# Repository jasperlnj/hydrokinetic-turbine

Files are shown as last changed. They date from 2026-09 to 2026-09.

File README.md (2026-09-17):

# Hydrokinetic Turbogenerator

This repository documents a run-of-river turbogenerator I designed, built, and field-tested over the course of a year. The core idea was to use 3D-printed vertical-axis turbines to drive a repurposed brushless hub motor acting as a three-phase generator.

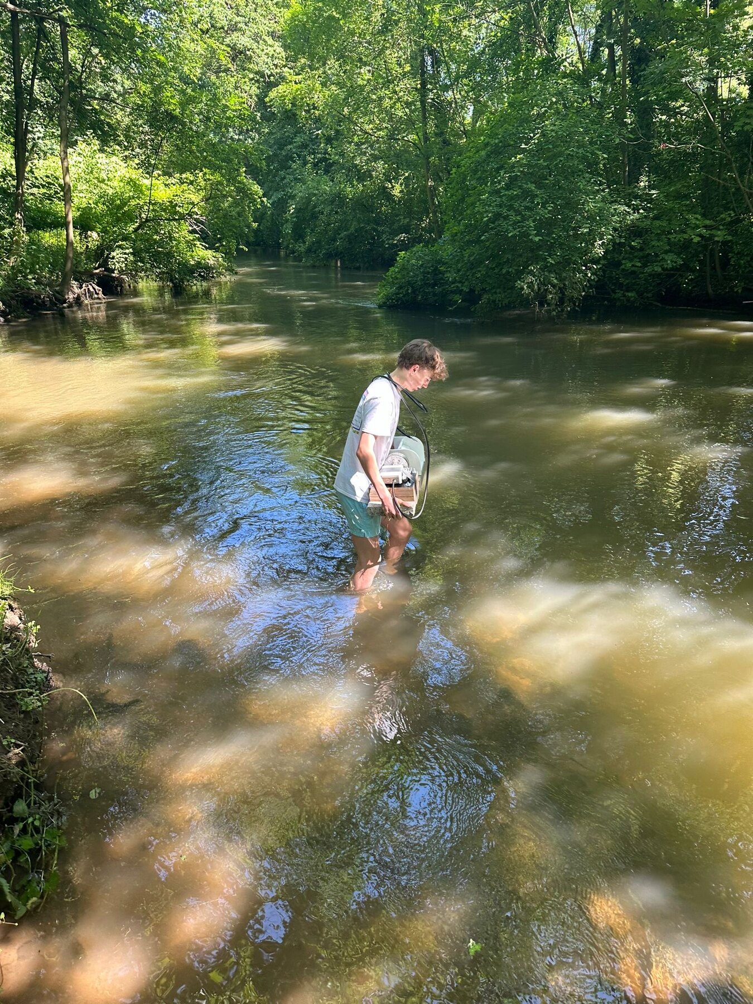
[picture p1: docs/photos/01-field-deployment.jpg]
Carrying the rig into the river Erft for the field test


**Spoiler alert: it didn't work.** The turbine refused to turn in the river.
But even though this was highly frustrating at first, it taught me some very valuable engineering lessons.

## Context

I originally built this for my *Projektkurs Naturwissenschaften* thesis at Friedrich-Wilhelm-Gymnasium in June 2024, right before I started my mechanical engineering degree at ETH Zürich.

The goal was to see if a small, fully 3D-printable hydrokinetic generator could produce usable power from a standard river current without needing a dam. I wanted to build something that could theoretically be carried out to a remote location to provide off-grid power.

If you read German, you can find my full original report here: [`docs/report-de.pdf`](docs/report-de.pdf).

## What I Built

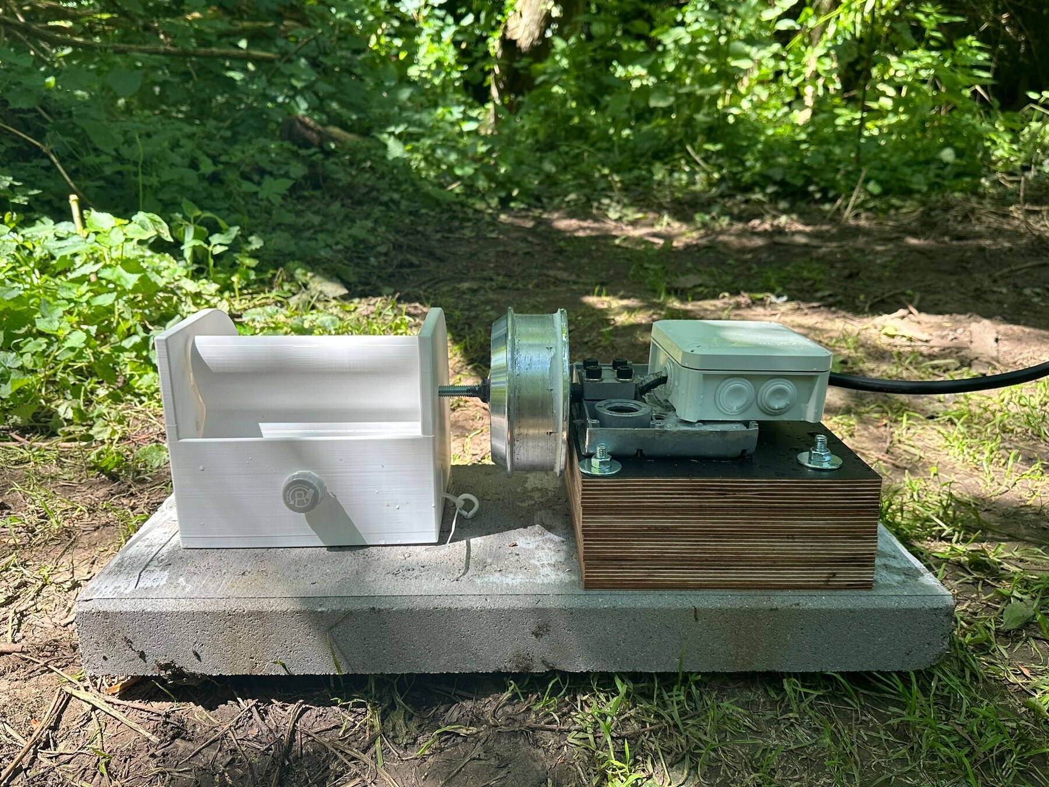
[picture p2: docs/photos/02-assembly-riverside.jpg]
The complete rig at the riverbank


The setup in the photo above (left to right) includes the 3D-printed turbine housing, the recycled electrical motor generator connected to the turbine using a threaded shaft, the motor mount, and a sealed junction box holding the rectifier.

The entire assembly is anchored to a heavy concrete paving slab, which was a late addition. My original design was way too light and kept getting pushed around by the flowing water. This way it was stable.

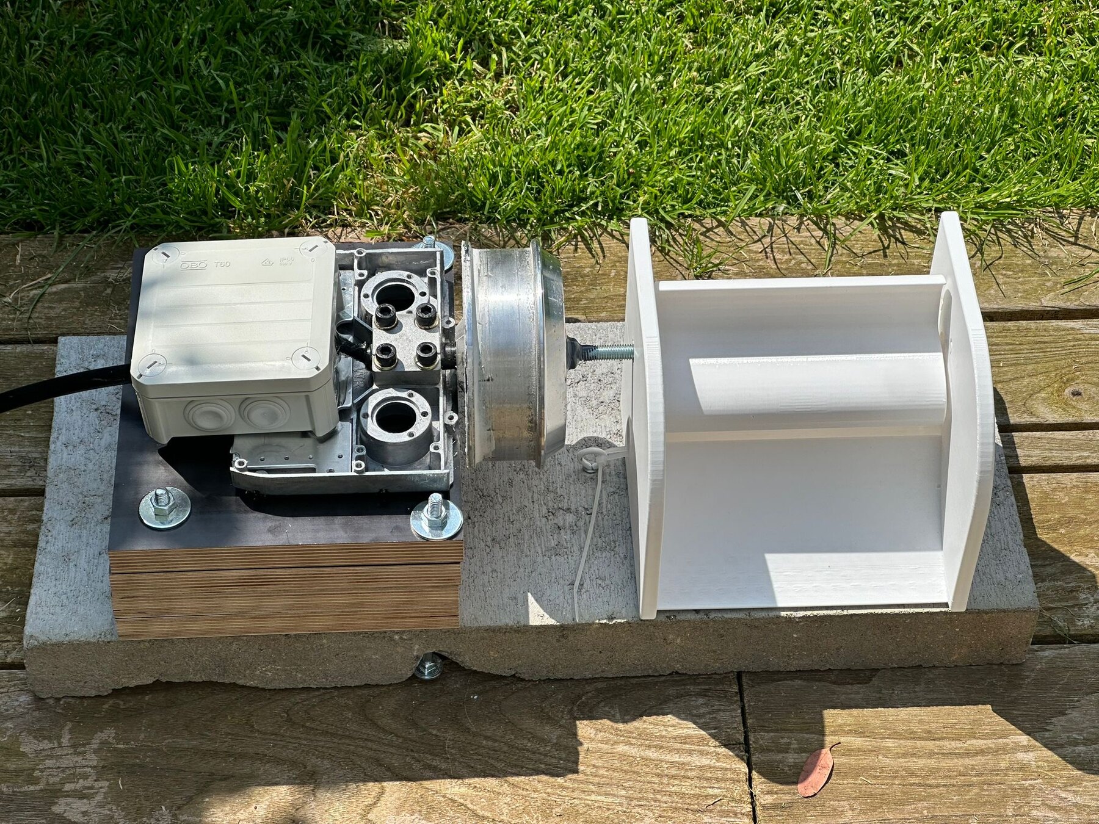
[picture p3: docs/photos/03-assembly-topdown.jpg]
Component layout from above


### The Turbines

I wanted to test different geometries, so I printed and weighed ten different vertical-axis turbine variants. I designed the main housing around a reversible fit, meaning I could quickly swap out any turbine by the riverside without having to rebuild the entire rig.

I played with three main variables:
- **Blade count:** 3, 4, 5, or 6 blades.
- **Blade shape:** Straight vs. curved.
- **Add-ons:** Guide vanes, higher mass or just plain.

All the variants fit into the same physical envelope (170 mm tall, 86–100 mm in diameter) and weighed between 90 g and 158 g. Unsurprisingly, more blades meant more mass. The variant with guide vanes was the heaviest by far—about 30% heavier than the plain three-blade version—which unfortunately put a significantly higher load on the generator's bearings.

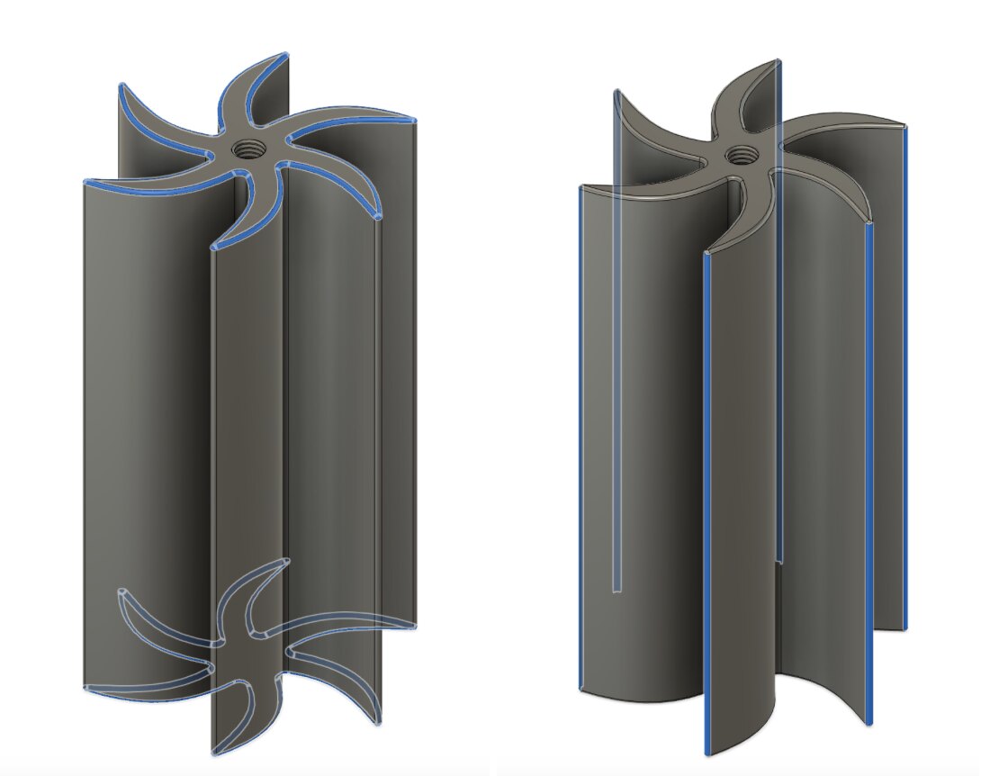
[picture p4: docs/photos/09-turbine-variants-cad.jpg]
Curved and straight blade variants


### The Generator & Rectifier

For the generator, I recycled a hoverboard hub motor, stripped it down, and ran it in reverse as a three-phase permanent magnet generator.

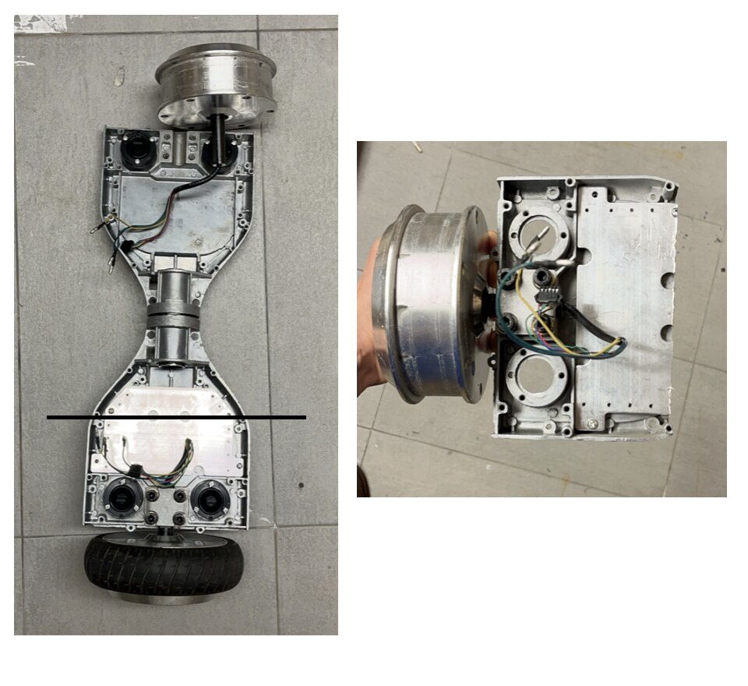
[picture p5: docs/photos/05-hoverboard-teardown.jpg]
Hoverboard hub motor teardown

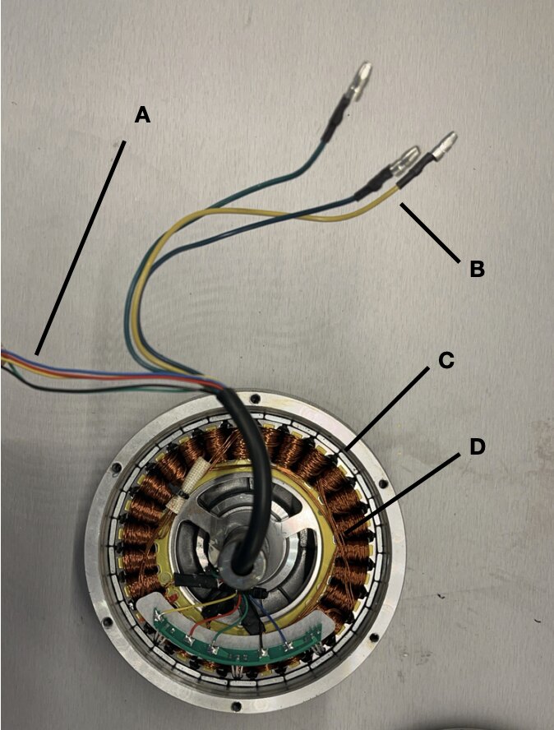
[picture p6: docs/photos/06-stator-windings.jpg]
Stator windings and phase leads


To make the three-phase AC output usable, I built a six-diode full bridge rectifier, sealed inside a waterproof junction box.
*(Circuit diagram: [`docs/rectifier-circuit.pdf`](docs/rectifier-circuit.pdf))*

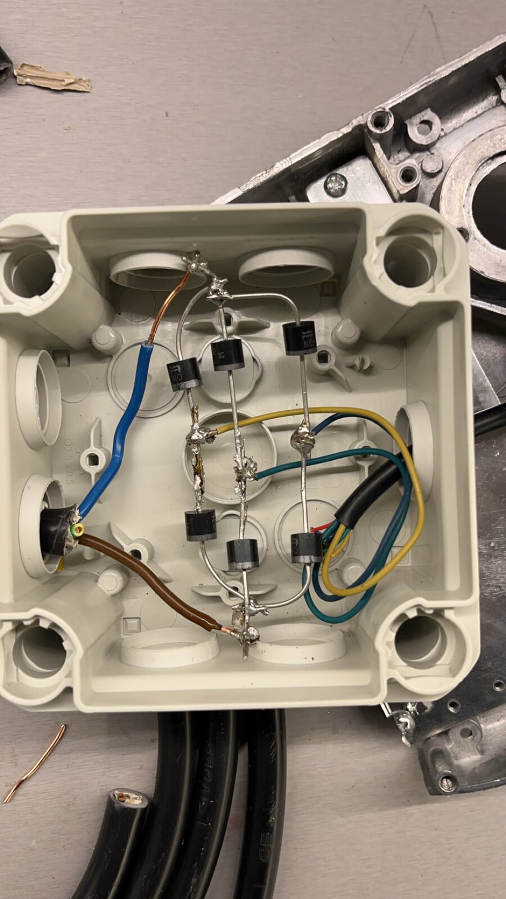
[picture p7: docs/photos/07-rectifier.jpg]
The rectifier bridge in its housing


## The Results

At first, things looked promising. When I gave it a good spin by hand, it generated 4.19 V across 3.41 A into a 20 Ω load. That is roughly **14.3 W**. The generator and the rectifier were doing their jobs perfectly.
I then took the setup out to the River Erft in Bergheim. I clocked the flow velocity at **1.468 m/s** (using the highly scientific method of timing a leaf floating down a 10-meter stretch). I sank the rig onto the riverbed so the turbine was about 20 cm below the surface, perfectly perpendicular to the flow.

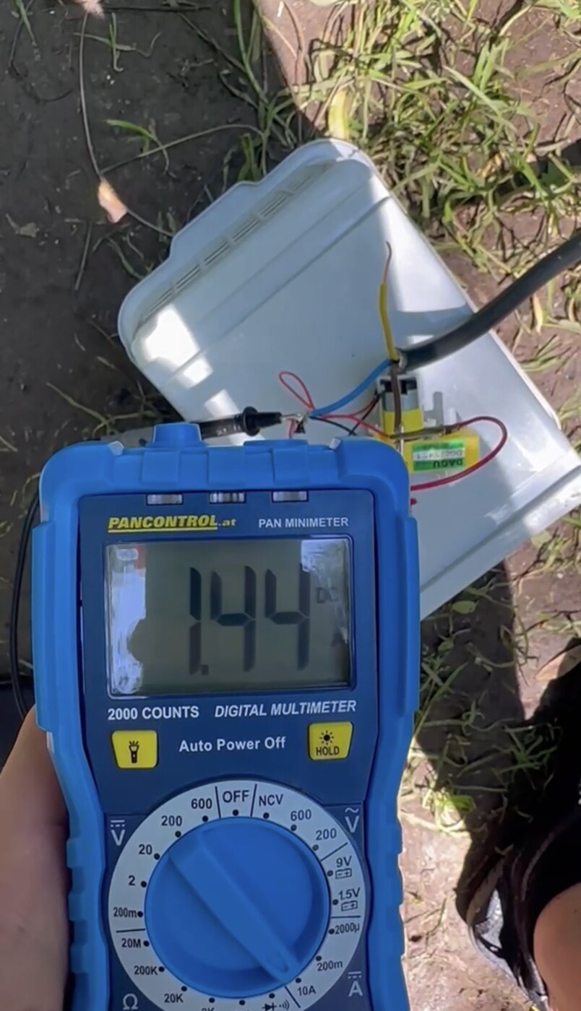
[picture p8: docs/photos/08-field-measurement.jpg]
Measuring output at the riverbank


When I reached under the water and spun it manually, it put out 1.64 V at 1.21 A (about **2.0 W**) and coasted for a second or two before the drag of the generator stopped it completely. The one major win was that the whole assembly stayed completely watertight, which was honestly the part I expected to fail first.

Because the turbine never maintained a steady speed under its own power, I couldn't measure a real power coefficient ($c_p$). If we assume a realistic $c_p \approx 0.1$, my original report projected it should have produced about 2.28 W.

## Why it didn't turn

The kinetic power passing through the turbine's swept area ($A = 0.01439 \text{ m}^2$, $v = 1.468 \text{ m/s}$) is:

$$P = \frac{1}{2}\rho A v^{3} = \frac{1}{2} \cdot 1000 \cdot 0.01439 \cdot 1.468^{3} \approx 22.8 \text{ W}$$

Even if we cap the efficiency at the theoretical Betz limit ($c_p \le 0.593$), there was roughly 13 W physically available to extract.

The real bottleneck was starting torque needed and not just the power available.
I fell into the trap of designing for power and completely ignored the torque required to get the system moving from a dead stop. Two specific mechanisms killed the rotation:

1. **Cogging torque:** A permanent-magnet hub motor has a really strong magnetic detent because the magnets want to align with the stator teeth. The river current has to break that static friction before anything moves and a stationary turbine generates drastically less torque than one that is already spinning.
2. **The diode bridge threshold:** The full bridge rectifier will not conduct until the generated voltage hits about 1.2–1.4 V. Below that speed, the generator is basically acts like a mechanical brake on the shaft without pushing any useful power out. The turbine has to fight its way out of this electrical "dead band" just to start doing work.

A basic power balance told me this project would work. A torque balance at zero speed would have told me it was doomed before I printed anything with the 3D-printer. Learning the critical distinction between a system being power-limited versus torque-limited at startup was my biggest takeaway from this whole endeavor, and it applies to almost any direct-drive machine.

## What I would do differently

If I were to build a version two, here is exactly what I would change:

- **Measure torque first:** I would put the generator on a bench, measure its exact cogging torque and no-load drag, and then size the turbine specifically to overcome that drag at my target flow velocity before committing to a blade geometry. Alternatively, I could reverse the process and select a motor matched to the turbine's output.
- **swap the motor:** Alternatively, I could reverse the process and select a motor matched to the turbine's output. Direct-driving a hoverboard motor designed for 20 km/h with a 1.5 m/s water flow is asking too much. I would either gear the turbine up to the generator, or find a motor with a much lower mechanical resistance.
- **Track RPM:** I only measured voltage and current. Without measuring the shaft's rotational speed, you cannot calculate $c_p$. And without $c_p$, you cannot actually compare how those ten different blade designs performed. I never got to this because the turbines weren't able to spin at all anyway.

## Repository Contents

```text
cad/ 13 STL files — 10 turbine variants, mount, housing shaft, rod
docs/ report (German), rectifier circuit diagram, photographs

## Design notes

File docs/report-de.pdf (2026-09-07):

# Design und Konstruktion

# eines hydrokinetischen Turbogenerators

Jasper Laurin Nörgaard Jörgensen

Friedrich-Wilhelm-Gymnasium

Projektkurs Naturwissenschaften

Q1

Betreuung: Herr Roseneck

10. Juni 2024

## Inhaltsverzeichnis

1 Eigenständigkeitserklärung | 3
2 Einleitung | 4
3 Theoretischer Rahmen | 6
4 Methodik | 13
5 Ergebnisse - Analyse und kritische Betrachtung | 25
6 Fazit | 28

7 Literaturverzeichnis | 29

## 1 Eigenständigkeitserklärung

Hiermit bestätige ich, dass ich die vorliegende Arbeit selbständig verfasst und keine anderen als die angegebenen Hilfsmittel benutzt habe. Die Stellen der Arbeit, die dem Wortlaut oder dem Sinn nach anderen Werken (dazu zählen auch Internetquellen) entnommen sind, wurden unter Angabe der Quelle kenntlich gemacht.

Datum, Unterschrift

## 2 Einleitung

### 2.1 Motivation, Projektbeschreibung und Zielsetzung

Eines der größten Probleme und Aufgaben des 21. Jahrhunderts ist es, die Nachfrage nach Elektrizität zu decken. Jedoch ist die endgültige Erschöpfung von traditionellen Energiequellen wie fossilen Brennstoffen unvermeidlich.
Nachhaltig erzeugte Elektrizität bietet eine Möglichkeit, die sozialen und wirtschaftlichen Entwicklungsprozesse zu stärken und dabei einen schonenden Umgang mit der Umwelt sowie dem globalen Klimawandel zu pflegen. Dabei entstehen deutlich weniger Emissionen, wie CO2, SO2 oder andere Nebenprodukte, die in der Ozonschicht abgelagert werden. Erdgas, Kohle oder Öl

tun dies jedoch und sind trotzdem die Quelle für mehr als 4/5 der Stromproduktion, wie im Bericht der International Energy Agency dargelegt [1].

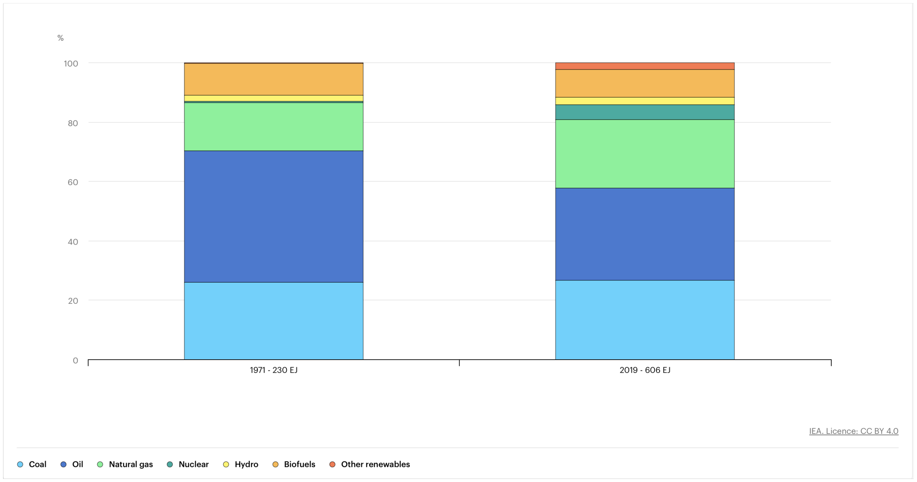
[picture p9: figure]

Abbildung 1: Stromerzeugungsquellen, IEA 1971 vs. 2019 [2]

Daher ist nachhaltig erzeugte Energie für die Erreichung der Millenniums-Entwicklungsziele (eng. Millenium Development Goals, MDGs) und der nachhaltigen Entwicklungsziele (eng. sustainable development goals, SDGs) von großer Bedeutung. Die MDGs waren acht internationale Entwicklungsziele, die im Jahr 2000 von den Vereinten Nationen gesetzt und bis 2015 erreicht werden sollten. Die SDGs, die 2015 verabschiedet wurden, bestehen aus 17 Zielen, die bis 2030 erreicht werden sollen, um Armut zu beenden, den Planeten zu schützen und Wohlstand für alle zu sichern.
Laut einer aktuellen Studie der Internationalen Energieagentur (IEA, 2023) haben Stand 2023 rund 750 Millionen Menschen, hauptsächlich in Entwicklungsländern, keinen Zugang zu Elektrizität [1]. Bis 2019 schien der Zugang zu Elektrizität drastisch zu wachsen, doch globale Krisen wie die COVID-19-Pandemie und die globale Energiekrise, ausgelöst durch die Invasion Russlands in der Ukraine, führten zu erheblichen Rückschlägen. Besonders in Ländern wie der Demokratischen Republik Kongo, Äthiopien, Sudan, Tansania und Uganda kam es zu erheblichen Rück-

schlägen, obwohl diese Länder teilweise Zugang zu Flüssen, einer potenziellen Energiequelle, haben. Sudan beispielsweise verfügt über rund eine Million Hektar Oberflächenwasser, wobei der wichtigste Anteil ein 2.000 km langer Abschnitt des Nils und seiner Nebenflüsse ist. Fast die

Hälfte des Nilbeckens liegt innerhalb der Grenzen des Sudans [3]. Obwohl erneuerbare Energien bereits ausführlich untersucht wurden, wurde der hydrokinetischen Energie noch nicht genügend Aufmerksamkeit geschenkt. Das Wasserkraftpotenzial liegt zwischen 25,48 Petawattstunden pro Jahr (PWh/Jahr) und 184,17 PWh/Jahr [4]. Der größere Fokus bei erneuerbaren Energien liegt in der Regel auf Wind- und Solarenergie. Wasserkraft ist zwar aktuell die größte Quelle für erneuerbare Energie, jedoch wird die Energie in der Regel durch den Bau großer Dämme genutzt [1] [5]. Dabei gibt es noch viele weitere Möglichkeiten, die Kraft von Wasser zu nutzen.

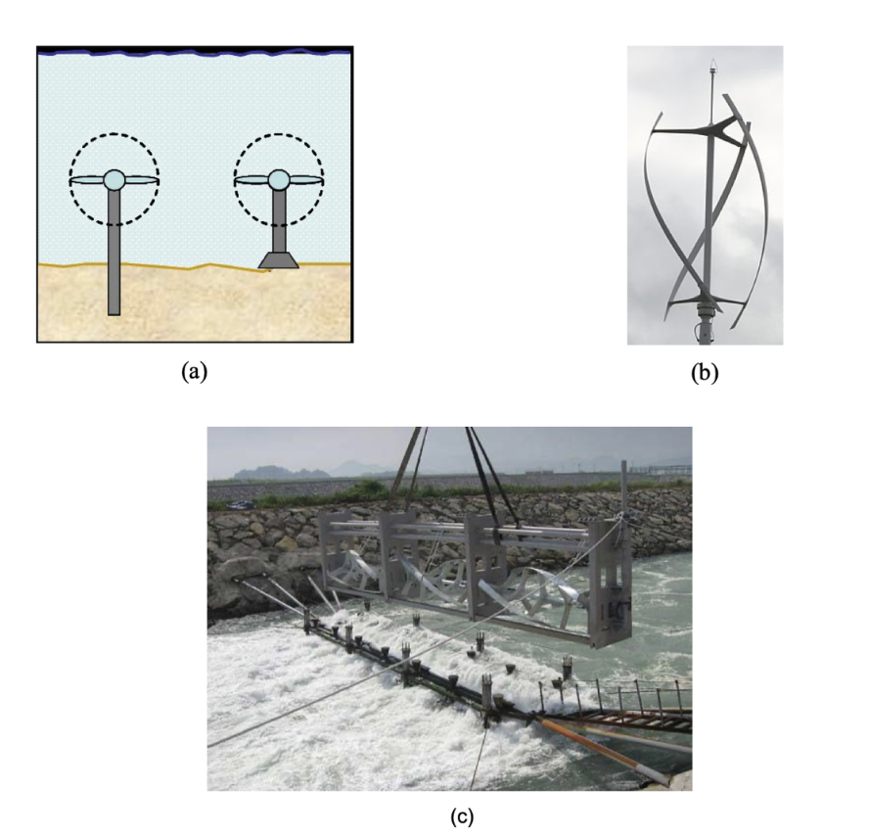
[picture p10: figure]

Abbildung 2: Beispiele für Wind-, Fluss- und Gezeiten-Generatoren [3]

(a) am Boden montierter Generator mit horizontaler Achse, (b) Gorlov-Turbine als vertikal ausgerichtete Windturbine und (c) Gorlov-Turbine als horizontal ausgerichtete Flussturbine.Der Input-Ressourcenfluss von Wasser ist zwar langsamer als der von Wind- oder Solarenergie, aber er profitiert davon, dass er deutlich zuverlässiger ist und eine Dichte hat, die bis zu 950 Mal so hoch ist wie die von Luft. Die höhere Dichte des Wassers hat zur Folge, dass es bei gleichem Volumen eine größere Trägheit besitzt, was zur Folge hat, dass mehr Energie pro Kubikmeter transportiert und umgewandelt werden kann. Diese Eigenschaft macht Wasserkraft besonders effizient und leistungsfähig.
Die Zuverlässigkeit von Wasserkraftwerken ist ein entscheidender Vorteil, da sie im Gegensatz zu vielen anderen erneuerbaren Energiequellen eine stetige und vorhersagbare Energieproduktion ermöglichen. Dies ist besonders wichtig, weil die Unzuverlässigkeit und Variabilität von Windund Solarenergie eines der größten Probleme dieser Technologien darstellt. Wasserkraftwerke hingegen sind eine der Schlüsseltechnologien für eine stabile und kontinuierliche Energieversorgung und tragen erheblich zur Netzstabilität bei.
Diese Projektarbeit fokussiert sich auf die Umwandlung von hydrokinetischer Energie in elektrische Energie und versucht dabei, die Frage zu klären, ob Kleinwasserkraft eine stromnetzunabhängige Lösung für die essentielle Stromversorgung sein kann.Gerade in Krisensituationen könnten Kleinwasserkraftanlagen eine große Chance bieten, da für kritische Strukturen wie medizinische Versorgung oder drahtlose Kommunikation eine zuverlässige Energiequelle entscheidend ist, da Strom konstant benötigt wird, und ebendies ist ein Vorteil von Wasserkraft. Ein oder mehrere 3D-druckbare Wasserkraftwerke könnten an Krisenorte gebracht werden, an denen Elektrizität gebraucht wird. In Krisensituationen könnte durch solche Mini-Wasserkraftanlagen insbesondere die medizinische Behandlung, die Elektrizität benötigt, gewährleistet werden.

## 3 Theoretischer Rahmen

Im Folgenden werden die wichtigsten Aspekte zum Verständnis dieses Projektes erläutert.

### 3.1 Wasserkraft

Grundsätzlich unterscheidet man bei Wasserkraft zwischen zwei Hauptbereichen: der konventionellen Wasserkraft, die auf dem Bau von Dämmen beruht, und der hydrokinetischen Wasserkraft, mit der sich dieses Projekt befasst.
Bei Turbinen unterscheidet man zwischen horizontalen und vertikalen Turbinen. Bei horizontalen Turbinen liegt die Achse parallel zur Strömung, während sie bei vertikalen Turbinen orthogonal zur Strömung liegt.
Im Folgenden werde ich fünf der wichtigsten bereits existierenden Wasserturbinen zum späteren Vergleich erklären. Hierbei werde ich mich auf Entstehung und Nutzung konzentrieren. Wasserturbinen in Staudämmen unterscheiden sich zwar, folgen aber der gleichen Idee: Wasser wird in einem Fluss durch den Bau eines Dammes gestoppt. Somit kann Energie in Form von potenzieller Energie gespeichert werden, die bei Durchlassen des Wassers erst in Bewegungsenergie und dann mithilfe eines Turbogenerators in elektrische Energie umgewandelt werden kann. Ein Vorteil von Dämmen ist, dass große Mengen an Energie nach freiem Willen in elektrischen Strom umgewandelt werden können. Dabei werden jedoch oft die Umwelt und der Lebensraum von Tieren, Menschen und Pflanzen beeinflusst. Staudämme verursachen Veränderungen in abiotischen Teilen von Fluss-Ökosystemen, wie Wasserqualität, Geomorphologie (Erdoberfläche) und Hydrologie, welche sich dann wiederum auf biotische Teile der Fluss-Ökosysteme auswirken, wie Flora

und Fauna, einschließlich Menschen [6].
Alternative Turbinen hingegen nutzen nicht Staudämme, sondern wandeln Bewegungsenergie direkt in elektrischen Strom um. Hohe Wirkungsgrade oder Leistungen, wie es sie bei Staudämmen gibt, gibt es bei Ihnen jedoch eher nicht. Dies liegt daran, dass sie nicht so stark in das Ökosystem des Flusses eingreifen und dementsprechend nicht 100% des Wassers so gezielt

durch sie fließen, wie es bei Staudämmen erreicht werden kann.

### 3.1.1 Francis-Turbine

Die Francis-Turbine ist eine Vertikal-Achsen-Turbine, die im Jahre 1849 von dem angloamerikanischen Ingenieur James B. Francis entwickelt wurde. Sie zählt zu den weltweit am weitesten verbreiteten Turbinen. Das Wasser wird durch einen Leitapparat mit verstellbaren Schaufeln auf

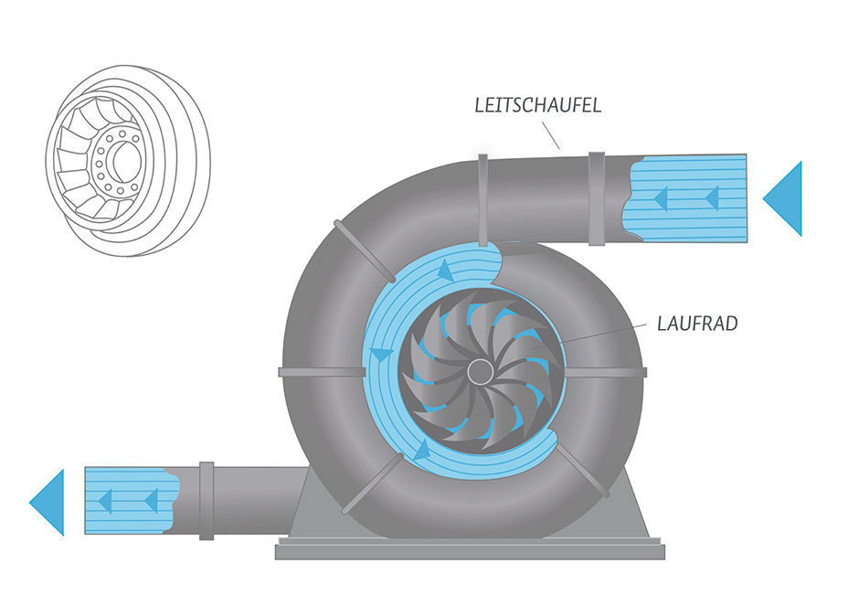
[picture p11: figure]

Abbildung 3: Funktion einer Francis-Turbine [7]

die gebogenen Schaufeln des Laufrads geleitet. Der Wasserzufluss erfolgt meist über ein Spiralgehäuse, und hinter dem Laufrad befindet sich ein sogenanntes „Saugrohr“. Francis-Turbinen können bei Fallhöhen bis zu 800 Metern und Durchflüssen bis zu 700 m³/s betrieben werden. Ihr Leistungsspektrum reicht von 10 kW bis über 700 MW [8]. Francis-Turbinen sind in der Regel sehr groß und können ein Gussgewicht von bis zu ca. 150 Tonnen erreichen. Ihr Wirkungsgrad liegt bei rund 90%. [7].

### 3.1.2 Kaplan-Turbine

Die Kaplan-Turbine ist eine Weiterentwicklung der Francis-Turbine. Genau wie die Francis-Turbine ist sie auch eine vertikale Turbine, bei der das Wasser vertikal ein- und ausströmt. Sie wurde 1913 vom österreichischen Ingenieur Viktor Kaplan entwickelt.

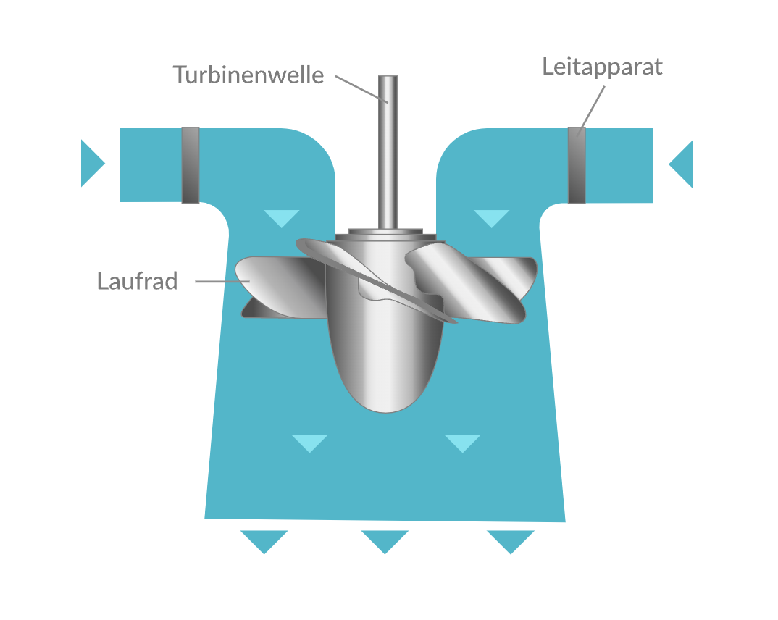
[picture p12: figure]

Abbildung 4: Funktionsweise einer Kaplan-Turbine [9]

Sie eignet sich besonders für kleinere Fallhöhen von maximal 80 m und große Wasserströme. Wie bei der Francis-Turbine sind auch hier die Flügel der Turbine verstellbar. Ihr Wirkungsgrad liegt zwischen 80 % und 95 %. Sie kann Leistungen zwischen 0,4 und 150 MW erbringen [10].

### 3.1.3 Pelton Turbine

Die Pelton-Turbine wurde 1879 vom US-amerikanischen Ingenieur Lester Pelton konstruiert. Sie kann sowohl als horizontale als auch als vertikale Turbine genutzt werden. Wasser wird durch eine oder mehrere Düsen kanalisiert, sodass es tangential auf die Turbine trifft. Hierbei wird ausschließlich die Bewegungsenergie genutzt.

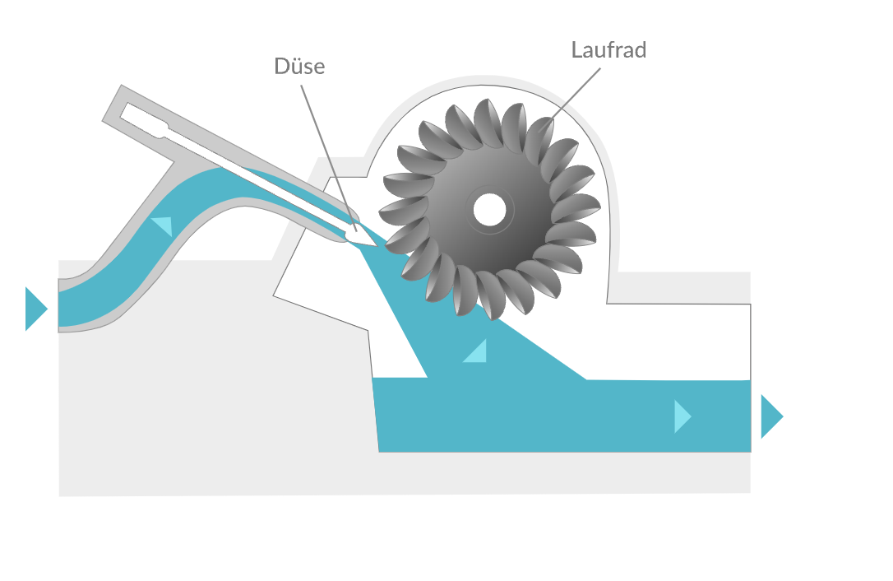
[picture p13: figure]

Abbildung 5: Funktionsweise einer Pelton-Turbine [11]

Die Pelton-Turbine eignet sich besonders gut für sehr hohe Wasserkraftwerke mit Fallhöhen zwischen 20 und 2000 m. Da die kinetische Kraft des Wasserstrahls abhängig von der Fallhöhe ist, wird sie in der Regel in Gebirgen verwendet. Bei einer Fallhöhe von 1000 m kann der Wasserstrahl beispielsweise eine Geschwindigkeit von 139 m/s erreichen. Die Pelton-Turbine kann bis zu 300 MW Leistung erreichen, da das Wasser aus der Düse die becherförmigen Schaufeln so trifft, dass der Wasserstrahl eine Ablenkung von fast 180° erfährt. Dadurch wird ein sehr hoher Wirkungsgrad von 85 % bis 90 % erreicht [12].

### 3.1.4 Durchströmturbine

Die Durchstömturbine wurde vom Ungarn Donát Bánki, vom Deutschen Fritz Ossberger und vom Australier Anthony George Maldon Michell am Anfang des 19. Jhdt. entwickelt.
Sie besteht aus einem walzenförmigen Laufapparat, welcher das Wasser steuert, das dann von außen nach innen durch das Laufrad fließt, bevor es auf der gegenüberliegenden Seite wieder austritt. In der Regel wird sie bei einer Fallhöhe von 2 bis 200 m und bei mittleren und schwankenden Durchflussmengen betrieben. Obwohl ihr Wirkungsgrad bei ca. 85 % liegt, kann die Durchströmturbine mit 3500 kW deutlich weniger Leistung als die anderen Turbinen erreichen. Dafür ist diese Turbine jedoch deutlich preiswerter und hat eine einfachere Konstruktion [13].

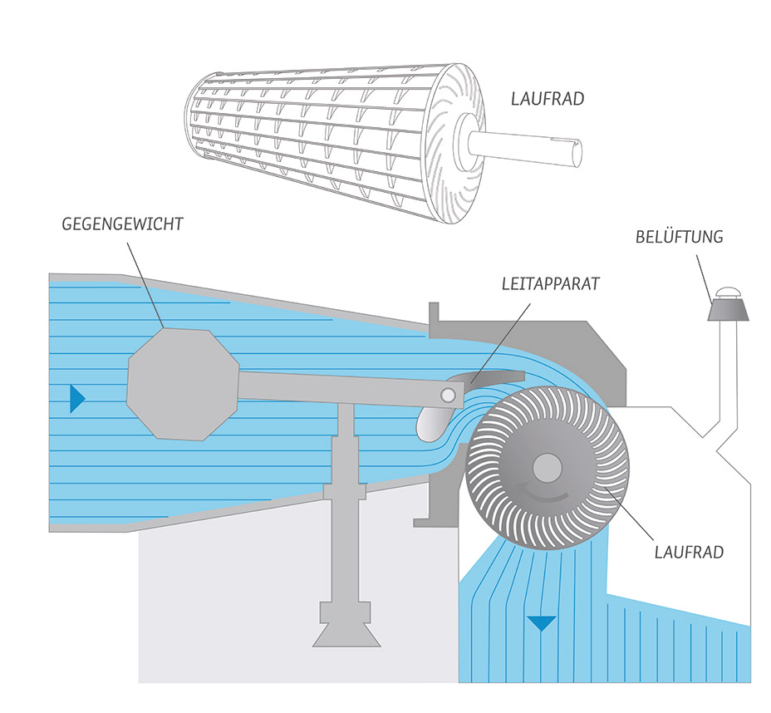
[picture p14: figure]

Abbildung 6: Funktionsweise einer Durchströmturbine [13]

### 3.1.5 Gorlov Turbine

Die Gorlov-Turbine ist eine neue Alternative zu den herkömmlichen Turbinen, die auf dem Bau von Dämmen beruhen. Sie wurde 1995 vom russisch-amerikanischen Ingenieur Alexander M. Gorlov patentiert. Sie kann sowohl als Wind- als auch als Wasserturbine benutzt werden.
Die Gorlov-Turbine ist eine Vertikalachsen-Turbine, die eine Weiterentwicklung der Darrieus-Wasserturbine darstellt. Die vertikalen Blätter der Darrieus-Turbine wurden durch spiralförmige Blätter ersetzt. Hiermit erzielte Gorlov einen Wirkungsgrad von ca. 35 %. Dies ist für eine Turbine dieser Art, die im freien Wasser steht und nicht in einen Damm eingebaut wird, eine sehr hohe Leistung. Außerdem ist die Gorlov-Turbine sehr umweltfreundlich, da sie die natürliche Wasserströmung nicht stark stört und somit weniger Einfluss auf Flora und Fauna hat. Die Herstellungskosten der Gorlov-Turbine können jedoch aufgrund der speziellen spiralförmigen Blätter und der Notwendigkeit robuster Materialien relativ hoch sein.

Abbildung 7: Aufbau einer Gorlov-Turbine [14]

### 3.2 Leistungsformel einer Turbine

Die Leistung einer horizontalachschen Wasserturbine kann mit der folgenden Gleichung bestimmt werden [15]:

PTurbine = 0, 5 · ρ · A · Cp · V

3

Wobei A die wirksame Querschnittsfläche der Turbine ist, ρ die Wasserdichte, V die Geschwindigkeit des Wassers und Cp der Leistungskoeffizient, also eine Konstante, die von Turbine zu Turbine unterschiedlich ist. Der Leistungskoeffizient ist wiederum direkt proportional abhängig von der Schnelllaufzahl, die das Verhältnis der Umfangsgeschwindigkeit zur Wassergeschwindigkeit angibt. Die Umfangsgeschwindigkeit ist die Geschwindigkeit eines Massepunktes auf einer Kreisbahn.

λ =

u
v

=

Umfangsgeschwindigkeit
Wassergeschwindigkeit

In Abbildung 7 ist der Leistungskoeffizient als Funktion der Schnelllaufzahl zu sehen.
Die ideale Schnelllaufzeit, λ, liegt bei einer Wasserkraftturbine bei etwa λ = 2, im Gegensatz zu einer Windturbine, bei der sie etwa das Vierfache beträgt.
Beispielrechnung:
Bei einer Wasserdichte ρ = 1000 kg/m³
, einer Querschnittsfläche A = 0.01 m² , einem Leistungskoeffizienten Cp = 0.3 und einer Wassergeschwindigkeit v = 1 m/s liegt die Leistung bei:

P = 0.5 × 1000 kg/m³ × 0.01 m² × 0.3 × (1 m/s) 3 = 1.5 Watt

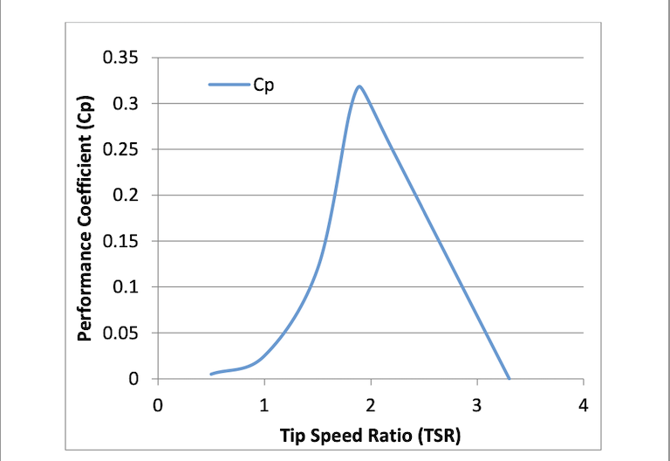
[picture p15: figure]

Abbildung 8: CP of a hydropower turbine [16]

### 3.3 Elektromagnetische Induktion

Eine zeitliche Veränderung eines Magnetfeldes führt zu elektrischem Strom. Diesen Vorgang nennt man elektromagnetische Induktion. Nimmt man also beispielsweise eine Leiterschleife und führt sie in ein magnetisches Feld hinein, so verschiebt die sogenannte Lorentzkraft die negativen Ladungen in ihr so, dass ein elektrisches Feld und damit auch eine Spannung entsteht. Die hierbei entstehende Spannung nennt sich Induktionsspannung.
Sie lässt sich mit der folgenden Formel berechnen:

E = −n

dΦ
dt

Φ ist der sogenannte magnetische Fluss und das Produkt aus der Querschnittsfläche A einer Spule bzw. Leiterschleife und dem senkrecht durch sie hindurchtretenden Magnetfeld B:

Φ = B · A

Der magnetische Fluss muss sich also ändern, damit eine Induktionsspannung entsteht.
Des Weiteren ist n die Windungszahl und dΦ
dt die zeitliche Ableitung des magnetischen Flusses. Das Minuszeichen vor der Gleichung kommt von der Lenz’schen Regel, die besagt, dass ein Induktionsstrom stets so gerichtet ist, dass sein Magnetfeld der Änderung des erzeugenden Ma-

gnetfeldes entgegenwirkt. Der Induktionsstrom bezieht seine Energie schließlich von diesem sich ändernden Magnetfeld. Somit ist die Lenz’sche Regel eine Folge des Energieerhaltungsgesetzes.

### 3.4 Elektrische Generatoren

Bei Generatoren muss man zwischen verschiedenen Sorten unterscheiden. Generell besteht ein einfacher Generator aus zwei Hauptbestandteilen: Magnet und Spule. Dreht sich der Magnet zwischen zwei feststehenden Spulen, so spricht man von einem Innenpolgenerator. Dreht sich die Spule hingegen zwischen den Magnetpolen, so spricht man von einem Außenpolgenerator. Bei dem Innenpolgenerator bzw. bürstenlosen Generator wird der innenstehende Magnet Ro-

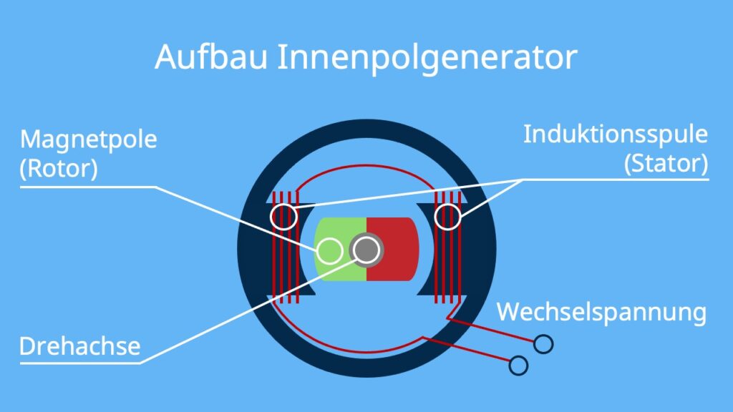
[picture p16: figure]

Abbildung 9: Aufbau eines Innenpolgeneratord [17]

tor genannt, da er der rotierende Teil des Generators ist. Dieser befindet sich zwischen zwei feststehenden Induktionsspulen, welche die Rolle des Stators übernehmen und den entstehenden elektrischen Strom als Wechselstrom weitergeben. Wird nun der Rotor durch von außen zugeführte mechanische Energie gedreht (senkrecht zum Stator), so ändert sich die Fläche der Spulen, die vom Magnetfeld durchsetzt wird. Nach dem Induktionsgesetz entsteht also eine Induktionsspannung, bei der sich A nach A · cos(α) ändert.

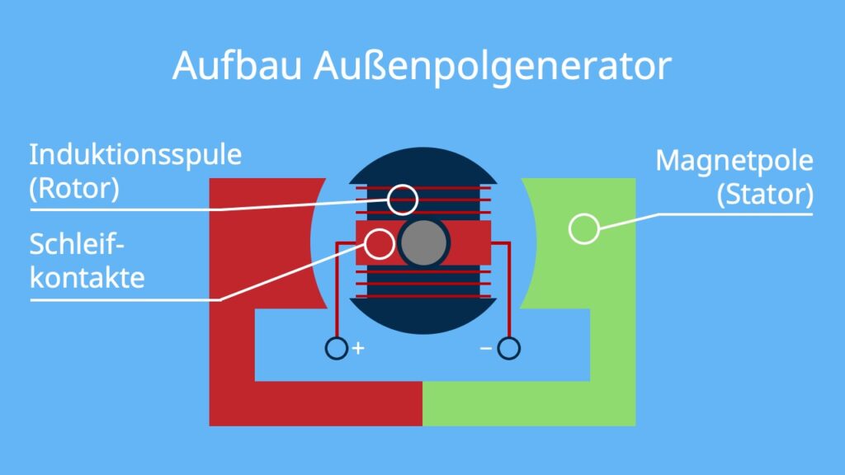
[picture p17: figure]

Abbildung 10: Aufbau eines Außenpolgnerators [17]

Beim Außenpolgenerator ist nun die Induktionsspule der Rotor und die Magnetpole fungieren als Stator. Ansonsten ist das Prinzip jedoch ähnlich. Der Rotor dreht sich senkrecht zum Stator, wodurch sich der magnetische Fluss ändert und eine Induktionsspannung entsteht. Diese ist wie beim Innenpolgenerator eine Wechselspannung, da die Spulen abwechselnd von den verschiedenen Polen des Magneten durchsetzt werden.
Ein entscheidender Unterschied zwischen dem Innen- und Außenpolgenerator ist, dass beim Außenpolgenerator ein Schleifkontakt verwendet werden muss, durch den der Strom fließen kann. Daher ist der Innenpolgenerator deutlich weniger anfällig für Probleme, da es weder zu Kontaktproblemen noch zur Funkenbildung kommen kann. Aus diesem Grund werde ich für dieses Projekt auch einen Innenpolgenerator nutzen.

Kombiniert man nun einen Generator mit einer Turbine, so spricht man von einem Turbogenerator.

## 4 Methodik

### 4.1 Turbogenerator Aufbau

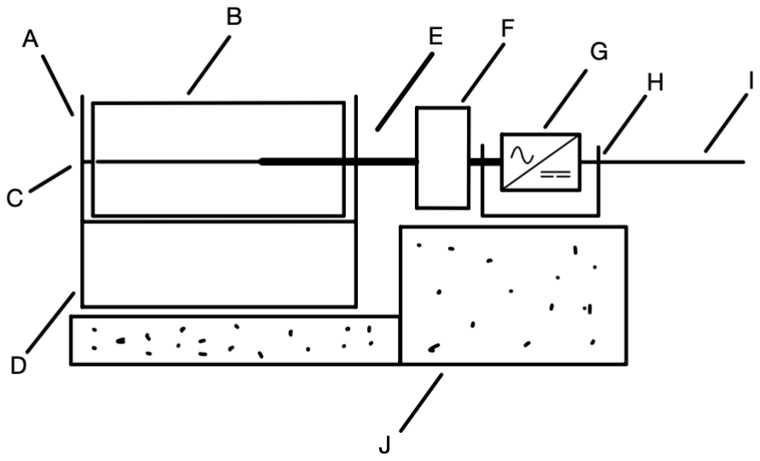
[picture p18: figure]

Abbildung 11: Detailzeichnung Aufbau des Turbogenerators

Der Turbogenerator nach meinem Design besteht aus einem Gehäuse für die Turbine (A), mit einer Halterung (C) für die Turbine (B) auf der einen und einer Gewindestange (E) auf der anderen Seite. Zur Turbine führt ein Wasserauflauf (D). Die Gewindestange ist so an der Turbine eingebaut, dass sie sich mit der Turbine dreht. Diese Gewindestange wiederum ist an einen Elektrogenerator (F) angeschlossen, der sich dementsprechend ebenfalls mit der Turbine mitdreht. Der Wechselstrom, der aus dem Generator kommt, wird in einer Vollbrückengleichrichtungsschaltung (G) zu Gleichstrom umgewandelt. Die Schaltung befindet sich in einer Abzweigsbox, die mit 2-Komponenten-Gel (H) gefüllt ist, um die Schaltung sowie die daran gelöteten Kabel vor Wasser zu schützen. Der Gleichstrom wird über ein wasserdichtes Erdkabel (I) abgeführt. Die gesamte Konstruktion befindet sich auf einem Stand (J).

### 4.2 Computer Aided Design der Turbinen und Halterung

### 4.2.1 Design der Turbinenhalterung

Um herauszufinden, welches Turbinendesign sich am besten zur Stromerzeugung eignet, habe ich mich dazu entschieden, eine Halterung (s. Abb) zu bauen, in der ich alle verschiedenen Turbinen variabel und einfach austauschen kann.
Die Halterung besteht aus zwei Seitenwänden (E), die das Wasser daran hindern, an der Turbine vorbeizufließen. Dadurch wird der Druck auf den Turbinenblättern erhöht, was zu einer schnelleren Umfangsgeschwindigkeit führt. Die Vorderseite ist jedoch oben abgerundet, um den Materialverbrauch zu reduzieren. Die Turbinen werden weiter hinten platziert, sodass die abgerundeten Wände keinen Einfluss auf die Wassermenge haben, die durchläuft.
Außerdem haben die Wände zwei Löcher, eines auf jeder Seite auf Höhe der Turbine. Das Loch auf der linken Seite (B) hat einen Durchmesser von 11 mm und dient dazu, die Metallstange einzuführen, die an den Elektrogenerator angeschlossen wird. Das Loch auf der rechten Seite (C) hat einen Durchmesser von 15 mm und dient dazu, eine schmale, 3D-gedruckte Stange einzuführen, die zur Stabilisierung der Turbine dient. Um diese zu befestigen, sind um das Loch herum 4 rechteckige Löcher (I) angebracht.

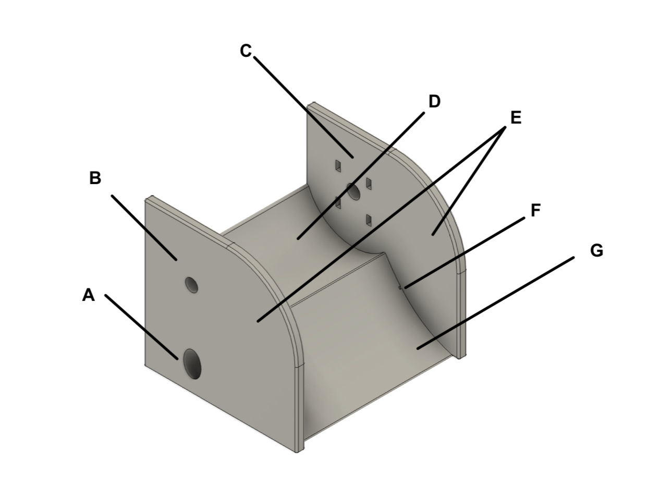
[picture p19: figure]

Abbildung 12: Frontansicht der Turbinen-Halterung in Fusion360

Alle anderen scharfen Ecken und Kanten sind ebenfalls abgerundet, mit einem Radius zwischen 1 und 3 mm. Dies verhindert, dass Teile abbrechen und die Umwelt verschmutzen, oder ein Sicherheitsrisiko für Lebewesen darstellen, die Kleinteile verschlucken könnten. Zudem spart dies Material ein, was besonders beim Druck von vielen Halterungen einen Unterschied macht. Vorne befindet sich ein parabelförmiger Auflauf (G), der das Wasser von unten nach oben leitet. Der Auflauf reicht bis unter die Stelle, an dem die Turbine platziert wird (D), um Wasser, das sonst unter der Turbine fließen würde, von unten und vorne gegen die Turbine zu leiten. Dies erhöht die Geschwindigkeit des Wassers nach der Kontinuitätsgleichung:

∂ρ
∂t + ∇ · (ρv) = 0 | (1)

Wobei ρ die Dichte und v das Geschwindigkeitsfeld ist. Dadurch, dass die Geschwindigkeit erhöht wird, die auf die Turbine trifft, wird die Umfangsgeschwindigkeit ebenfalls erhöht. Um zu testen, ob eine Parabel- oder Geradenform besser geeignet ist, sind an den Seiten des Auflaufs Vorrichtungen angebracht, um eine Geradenform einzusetzen. Vor dem Stand der Halterung sollte Erde oder Sand aufgehäuft werden, um Spannungen und Verwirbelungen zu vermeiden.
Hinter dem Auflauf befindet sich eine Kuhle, in die die Turbine eingelassen wird (D). Es ist absichtlich nicht die gesamte Turbine freigelegt, sondern nur der obere Teil. Der obere Teil soll sich in die gleiche Richtung wie der Wasserstrom bewegen, während der untere Teil in die entgegengesetzte Richtung fließen soll. Dadurch fließt weniger Wasser gegen den unteren Teil der Turbine, was zu einer höheren Umfangsgeschwindigkeit führt.
Der Körper der Halterung ist innen hohl mit einer Wandstärke von 1 cm. Dadurch wird Material eingespart, und es ist möglich, den Hohlraum mit einem Material zu füllen, das eine höhere Dichte
als Wasser hat. Nasssand eignet sich hierfür gut, da er eine Dichte von ca. 2 t/m³ | hat, was doppelt

so viel ist wie die Dichte von Wasser. Durch den schweren Körper sinkt die Halterung auf den Boden und ist dort fixiert.
Um das Befüllen zu ermöglichen, ist ein PCO 1881-Gewinde angebracht (H) [18], das auch bei einem Großteil kommerzieller Flaschen zu finden ist (s. Abb.). Durch die Verwendung dieses

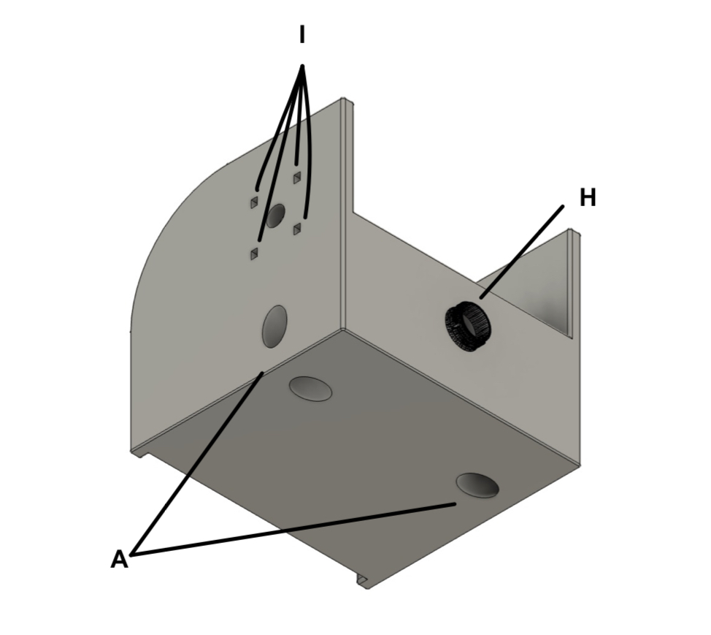
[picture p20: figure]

Abbildung 13: Rück Ansicht der Turbinenhalterung in Fusion360

beliebten Gewindes kann der Plastikdeckel einer Colaflasche beispielsweise als Verschluss des Körpers recycelt werden, was der Nachhaltigkeit dient.

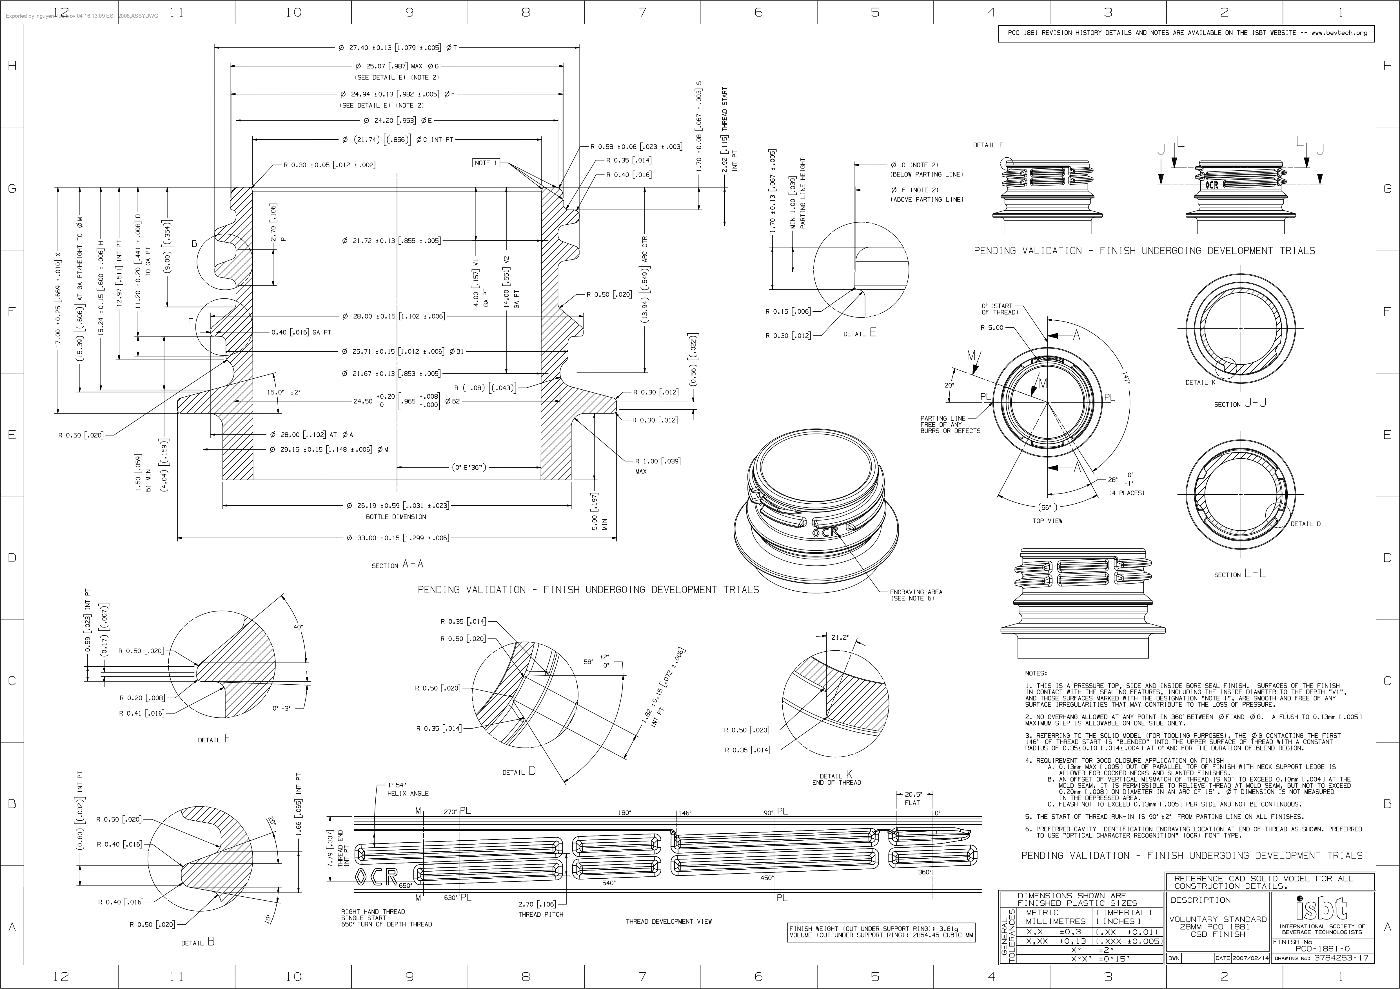
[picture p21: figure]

Abbildung 14: isbt Standard PCO 1881

Als zusätzliche Befestigungsmöglichkeit befinden sich am unteren Teil von beiden Seitenwänden jeweils ein Loch, das als Öse fungiert (A). Man kann beispielsweise Stöcke verwenden, um die Halterung durch die Ösen am Boden zu fixieren. Dabei sollte ein möglichst langer Stab oder Stock verwendet werden, denn je tiefer der Stab durch die Öse bis in den Boden geht, desto

stärker hält die Halterung am Boden.

### 4.3 Stabilisation der Turbine & Kugellager

Um die Turbine (D) zu stabilisieren, wird ein Stab (B) durch das rechte, breitere Loch der Halterung
(A) geführt und an der Wand der Halterung befestigt. Dieser Stab durchdringt auch die Turbine, wobei zwei Kugellager (C) zwischen Stab und Turbine montiert sind, um eine Drehbewegung der Turbine zu ermöglichen.
Da der Turbogenerator unter Wasser arbeiten muss, werden Kugellager aus Kunststoff verwendet, deren Kugeln aus Glas statt aus Metall bestehen. Kugellager aus Metall wären anfällig für Korrosion. Die Verwendung von Glaskugeln reduziert zwar die Drehfähigkeit aufgrund ihrer erhöhten Reibung, bietet jedoch auf mittelfristige Sicht aufgrund ihrer Korrosionsbeständigkeit deutliche Vorteile. Zudem sind sie für extreme Wetterbedingungen geeignet, mit einer Temperaturbeständigkeit von -40°C bis +80°C.

Abbildung 15: Detailzeichnung Turbine

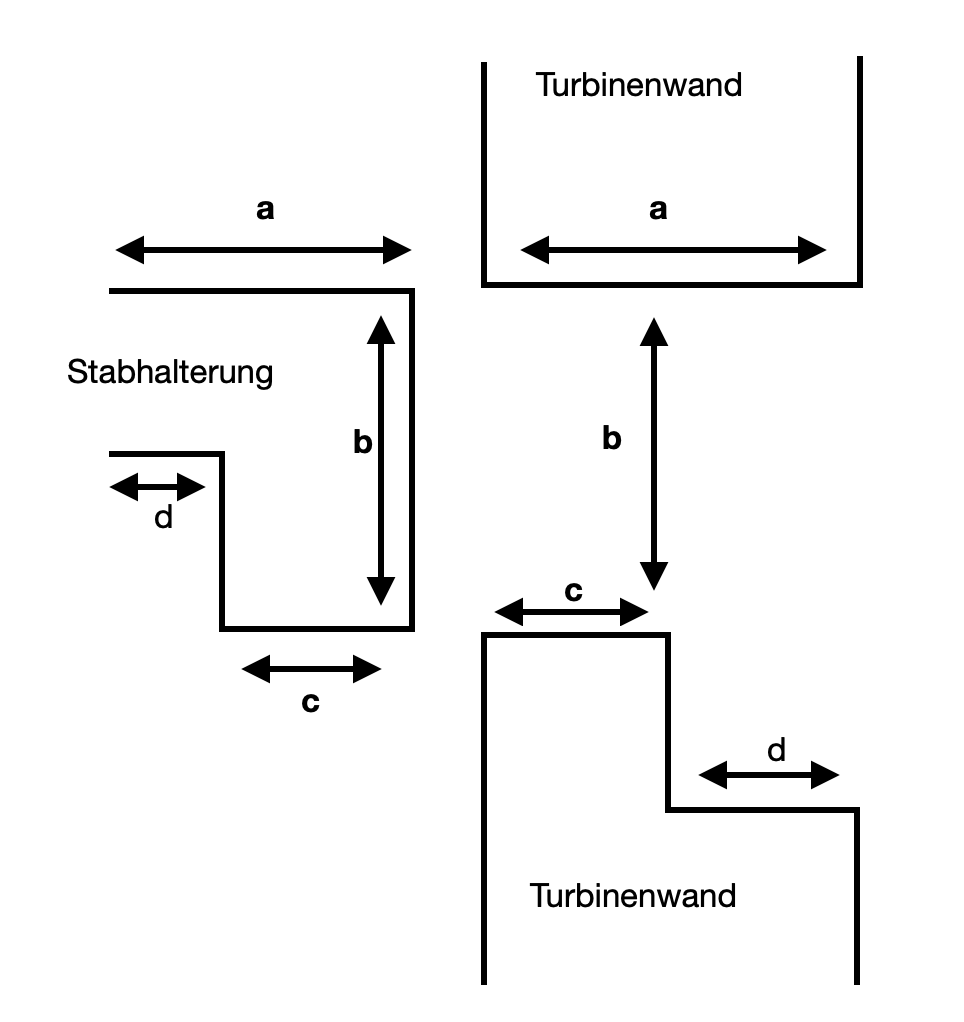
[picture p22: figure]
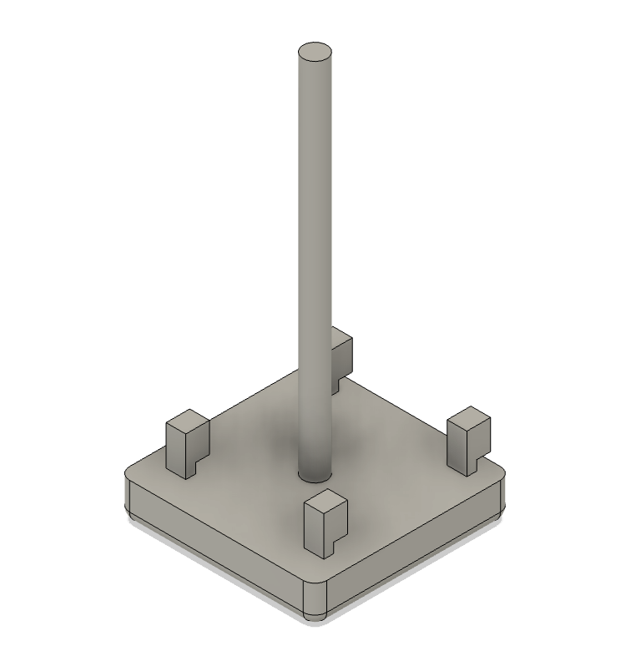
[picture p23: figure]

(a) Querschnitt Stabhalterung/Turbinenwand | (b) Stab (B)

Abbildung 16: Funktionsweise des Stabs

Die Gewindestange (E) trägt die Turbine auf der anderen Seite.
Der Innnendurchmesser d1 beträgt 6 mm, der Aussendurchmesser d2 beträgt 13 mm und die Breite b1 5 mm.

### 4.4 Design der Turbinen

Die Turbinen bestehen aus mehreren Turbinenschaufeln sowie einem Loch auf der rechten Seite mit einem Durchmesser von 13 mm, entsprechend dem Außendurchmesser des Kugellagers, und einem Loch auf der linken Seite mit einem Durchmesser von 10 mm (bezogen auf die Flussrichtung des Wassers). Das rechte Loch dient zur Aufnahme für den Stab. Da das Kugellager einen Außendurchmesser von 13 mm hat, hat das Loch den gleichen Durchmesser. Das linke Loch verfügt über ein ISO-M10-Gewinde. ISO ist der Standard für Gewinde, die in Europa verwendet werden. M10 ist die Größeneinheit, d. h. das Gewinde hat einen Durchmesser von 10 mm. Beim Design der Turbinen habe ich mich auf 5 Kernvariablen konzentriert, um ihren Einfluss auf die erzeugte Leistung zu untersuchen bzw. um sie so anzupassen, dass die Leistung möglichst hoch ist. Diese werde ich im Folgenden erklären.

### 4.4.1 Form/Abrundungen

Bei allen Turbinen habe ich darauf geachtet, dass die Seiten der Blätter sowie alle anderen scharfen Ecken, wie in Abb. gezeigt, abgerundet sind, genau wie bei der Halterung. Dabei haben alle

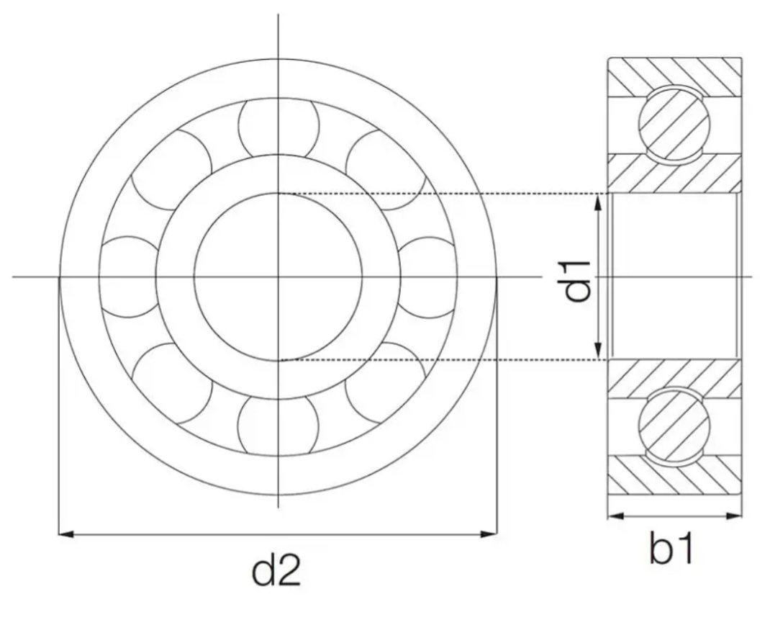
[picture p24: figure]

Abbildung 17: Kugellager Maße [19]

Abrundungen einen Radius von 1 mm.

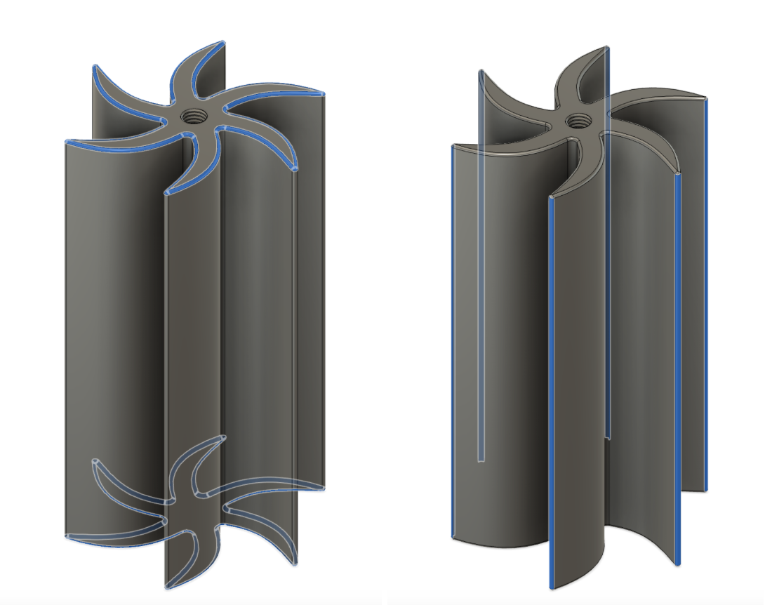
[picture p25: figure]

Abbildung 18: Abgerundete Kanten und Ecken

An den Stellen, an denen die Turbinenschaufeln aufeinander bzw. den Mittelteil treffen, befinden sich ebenfalls Abrundungen (vgl. Abb.). Grundsätzlich schafft eine abrupte Änderung der

Geometrie einen Bereich, in dem sich die Spannungen konzentrieren und einen Punkt des Versagens darstellen.

Abbildung 19: ohne vs. mit Mittelteilabrundung

Verrundungen schaffen einen allmählicheren Übergang und verringern dadurch den Faktor der

Spannungskonzentration. Sie werden die Spannungskonzentrationen nicht vollständig beseitigen, aber sie werden dazu beitragen, sie zu verringern und einen Fehlerpunkt weniger zu schaffen. Außerdem sollten die Abstände zwischen den Turbinenblättern gleich groß sein, damit sich die Turbine ausgeglichen dreht. Ungleichmäßige Abstände führen zu einer ungleichmäßigen Verteilung des Gewichts, was wiederum zu einem ungleichmäßigen Rotieren führt.
Die Turbinenblätter habe ich so dünn wie möglich gestaltet, ohne dass sie zerbrechlich werden.

### 4.4.2 Anzahl der Turbinenblätter

Die Anzahl der Turbinenblätter habe ich zwischen 3 und 6 Blättern variiert. Bei einem Blatt würde sich die Turbine offensichtlich nicht drehen, da das Blatt nur durch den Fluss nach hinten gedrückt würde. Daher habe ich keine einblättrige Turbine designt. Bei zwei Blättern wäre der hydrodynamische Druckausgleich nicht optimal. In bestimmten Positionen der Drehung wären die beiden Blätter gleichzeitig dem Wasser ausgesetzt, was zu einem symmetrischen Druckaufbau auf beiden Seiten führt. Dies bedeutet, dass es Momente gibt, in denen kein Blatt einen effektiven Vortrieb erzeugen kann, was die Rotation verlangsamt oder sogar stoppt.

### 4.4.3 Blattform

Was die Form der Turbinenblätter angeht, so gibt es für jede Anzahl an Blättern sowohl eine Turbine mit geradem Blatt als auch eine mit gekrümmtem Blatt. Bei dem gekrümmten Blatt war das Ziel, die hydrodynamische Effizienz zu maximieren.
Die Krümmung sollte so gestaltet sein, dass sie den hydrodynamischen Auftrieb maximiert und gleichzeitig den Widerstand minimiert. Ein gut gekrümmtes Blatt erhöht den Auftrieb, was zu einer besseren Energieumwandlung führt, und verringert den Strömungswiderstand, wodurch Verluste reduziert werden.

### 4.4.4 Masse der Turbinen

Die Masse der Turbinen ist wichtig, da eine höhere Masse auch mehr Kosten bedeutet. Außerdem belastet eine höhere Masse den Generator mehr, da er die Turbine trägt. Dies kann zu einer niedrigeren Umfangsgeschwindigkeit führen.

### 4.4.5 Leitblech

Um herauszufinden, ob ein Leitblech einen positiven Einfluss hat, habe ich am dreiblättrigen Design mit runden Blättern ein Leitblech angebracht. Dieses Leitblech ist auf jeder Seite 4 mm breit, sodass die effektive Länge der Turbine um 8 mm kürzer ist. Allerdings ist diese Breite wichtig, um Stabilität und Resilienz des Leitbleches zu garantieren.

### 4.4.6 Resultierende Turbinen

Turbine | Anzahl der Blätter | Blattform (Gebogen/Gerade) | Zusätzliche Merkmale
1 2 3 4 5 6 7 8 9 10 | 3 3 3 3 4 4 5 5 6 6 | Gebogen Gebogen Gebogen Gerade Gebogen Gerade Gebogen Gerade Gebogen Gerade | Mit Leitblechen Reduzierte Blattfläche

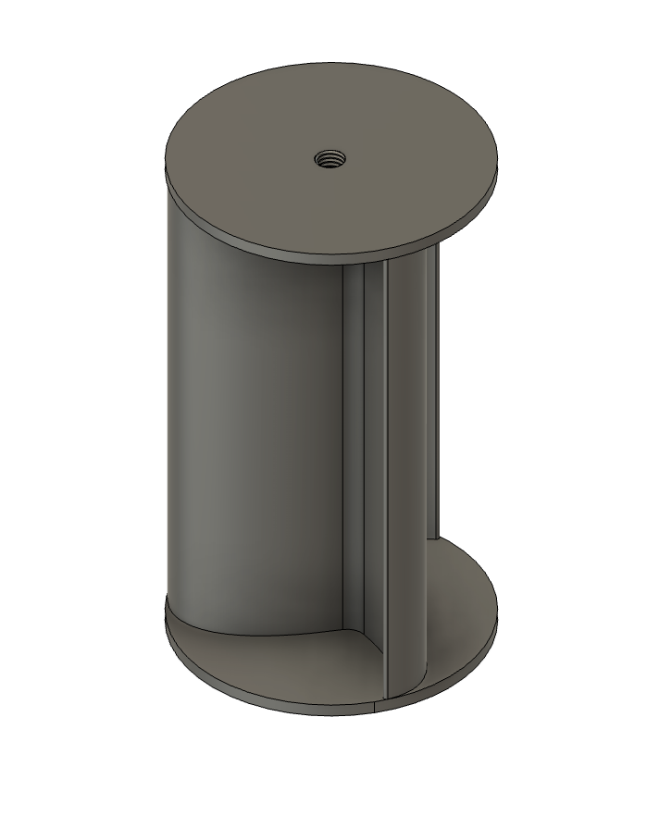
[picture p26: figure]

Abbildung 20: Turbine mit Leitblech

### 4.5 Material

Beim Material habe ich mich dazu entschieden, Polyethylenterephthalat (PETG) zu benutzen. Es ist genauso einfach zu drucken wie Polylactide (PLA), da es nur ca. 0,5% beim Abkühlen schrumpft [20] Im Gegensatz zu PLA ist PETG jedoch sehr wasserbeständig und eignet sich deswegen sehr für die Nutzung unter Wasser. Ein Nachteil von PETG ist, dass es leicht verkratzt, allerdings ist dies für die Nutzung als Turbogenerator irrelevant.

### 4.6 Generatorbau

Viele Generatoren verwenden heutzutage Elektromagneten anstelle von Permanentmagneten, da auf diese Weise das Erregerfeld reguliert werden kann, was dazu beiträgt, die Blindleistung zu minimieren. Blindleistung bezeichnet die Leistung in einem elektrischen Stromkreis, die aufgrund von Phasenverschiebungen zwischen Strom und Spannung erzeugt wird, ohne tatsächlich Arbeit zu verrichten. Diese Elektromagneten werden normalerweise zu Beginn von einer Batterie gespeist und anschließend vom erzeugten Strom.

### 4.7 Hoverboard Motor als Generator

Für dieses Projekt werden jedoch Permanentmagneten benötigt, da keine bereits geladene Batterie zur Verfügung steht und der Turbogenerator an jedem Ort funktionieren muss. Daher eignet sich der Generator bzw. der Motor, der in einem Hoverboard verbaut ist, sehr gut. Dieser verwendet einen Innenpolgenerator mit Permanentmagneten aus Neodym. Obwohl das Prinzip dem bereits beschriebenen Elektrogenerator ähnelt, rotieren hier die Magnete um die Spulen. Die verbauten Kugellager sind ebenfalls von hoher Qualität, wenn auch nicht wasserdicht. Der Motor ist zudem auf eine niedrige Drehzahl ausgelegt, was für dieses Projekt vorteilhaft ist, da niedrige Wasserfließgeschwindigkeiten zu einer niedrigen Drehzahl führen.
Hoverboards und insbesondere ihre Motoren sind üblicherweise ziemlich wasserdicht. Ein Nachteil des Hoverboard Motors ist allerdings, dass er einen 3 Phasigen Wechselstrom abgibt. Dreiphasenwechselstrom ist eine Art von elektrischem Strom, der aus drei Wechselströmen besteht, die um jeweils 120 Grad phasenverschoben sind. Diese Anordnung ermöglicht eine gleichmäßige und kontinuierliche Energieübertragung, was besonders für elektrische Netze und

Motoren vorteilhaft ist. In einem dreiphasigen System gibt es drei Leitungen, die jeweils einen der drei Phasenströme führen, sowie oft eine Neutralleitung. Die Phasenverschiebung sorgt dafür, dass die Summe der Ströme zu jedem Zeitpunkt null ist, wodurch die Effizienz und Stabilität des Stromnetzes verbessert wird. Dreiphasenwechselstrom ist die Standardmethode für die Stromübertragung in vielen industriellen und kommerziellen Anwendungen.

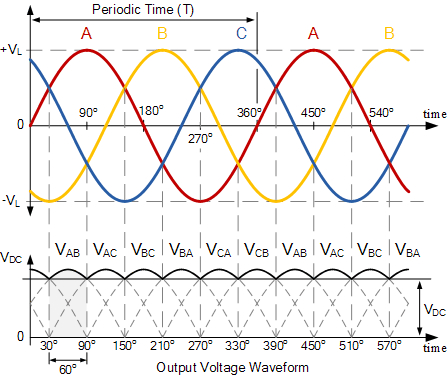
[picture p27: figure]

Abbildung 21: Dreiphasenwechselstrom vor und nach Gleichrichtung [21]

Diese Art von Strom macht es allerdings schwerer, einen Verbraucher anzuschließen, da die meisten Verbraucher nicht für einen solchen Strom gebaut sind. Batterien beispielsweise müssen mit Gleichstrom geladen werden.

Abbildung 22: Hoverboardrad Innenansicht

Um an den Motor (s. Abb. 22) heranzukommen, muss erstmal das Hoverboard auseinandergeschraubt werden. Des Weiteren muss alle Elektronik entfernt werden, bis nur noch die Dreiphasenwechselstrom Kabel (B) übrig sind. Zusätzlich gibt es noch mehrere kleine Kabel (A) die aus dem Rad herauskommen. Diese sind jedoch für dieses Projekt unwichtig, da sie lediglich zur Steurung der Drehrichtung der Räder bzw. Fahrtrichtung des Hoverboards wichtig sind. Ansonsten sieht man auf Abb. 22 außen die Permanentmagneten (C) und innen die Spulen (D).
Das Rad ist an einem Metallgehäuse befestigt, welches mit einem Winkelschleifer in der Mitte durchtrennt werden musste, um den Motor auf dem Stand der Halterung zu befestigen.
Um eine zuverlässige Wasserdichtigkeit zu gewährleisten, habe ich alle potenziell undichten Stöße des Hoverboard Motors mit Silikon abgedichtet (s. Abb. 24).

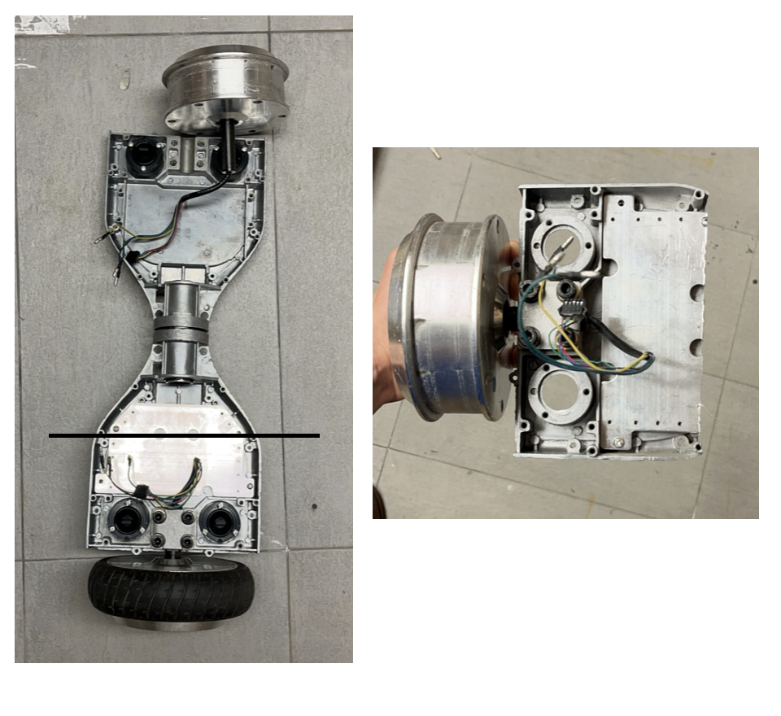
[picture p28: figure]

Abbildung 23: Hoverbord vor und nach Durchteilen

Abbildung 24: Hoverboardrad Abdichtung aussen

### 4.8 Gleichrichtung des Stroms

3 Phasen-Wechselstrom eignet sich für viele industrielle Anwendungen wie Motorsteuerung oder Batterieladung, die einen höheren Strombedarf haben als ein einphasiger Gleichrichterkreis liefern kann. Allerdings ist das Ziel dieses Projektes, Batterien aufzuladen oder eine Lampe anzutreiben oder medizinische Geräte mit Elektrizität zu versorgen, und diese arbeiten mit Gleichstrom. Um den 3-Phasen-Strom, der durch den Hoverboard-Generator erzeugt wird, umzuwandeln, braucht man einen sogenannten Vollbrücken-Gleichrichter.
Ein Vollbrückengleichrichter benutzt Dioden, elektronische Bauteile, die Strom nur in eine Richtung durchlassen. Schließt man einen Wechselstrom an eine Diode, so fließt der Strom nur dann, wenn er positiv und über einer gewissen Mindestspannung ist. Ist die angeschlossene Spannung unter diesem Mindestspannungswert bzw. negativ, so fließt kein Strom. Schließt man nun den Wechselstrom (grüne Pfeile) jeweils zwischen zwei Dioden (rotes Dreieck unter Strich) und diese wiederum parallel zueinander, so erhält man einen Vollbrückengleichrichter. In abb.21 sieht man unten, wie der resultierende Gleichstrom dann aussieht.

Abbildung 25: Vollbrückengleichrichtungsschaltung Schaltkreis [22]

Zusätzlich könnte man noch einen Kondensator mit einbauen, um eine gleichmäßige Spannung zu bekommen, aber für dieses Projekt ist dies nicht notwendig, da keine konstante Spannung gebraucht wird.

Abbildung 26: Vollbrückengleichrichtungsschaltung in Abzweigbox, angeschlossen an 3 Phasen Wechselstrom und Erdkabel

Ich habe für meine Vollbrückengleichrichtungsschaltung sechs Dioden wie abgebildet zusammengelötet. Die Anode ist hier an das blaue Kabel und die Kathode an das braune Kabel gelötet.

### 4.9 Verbindung Generator und Turbine

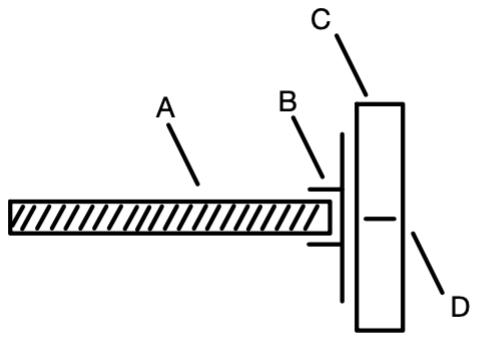
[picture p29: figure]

Abbildung 27: Detailzeichnung Halterung Gewindestange

Um die Turbine mit dem Generator zu verbinden, wird eine M10 Gewindestange (A) genutzt, welche auf eine M10 Mutter geschraubt ist (B). Beide sind mit industriellem 2-Komponenten-Kleber mit einer Stärke von 180 kg/cm² an die Turbine (C) auf der Höhe der Drehachse (D) geklebt.

Abbildung 28: Hoverboardrad Befestigung Gewindestange

### 4.10 Kompletter Versuchsaufbau

### 4.10.1 Stand

Der Stand besteht aus einer Betonplatte, auf welcher die Turbine steht. Durch das Gewicht der Betonplatte kann sich der Turbogenerator nicht durch die Strömung verschieben. Um den Genera-

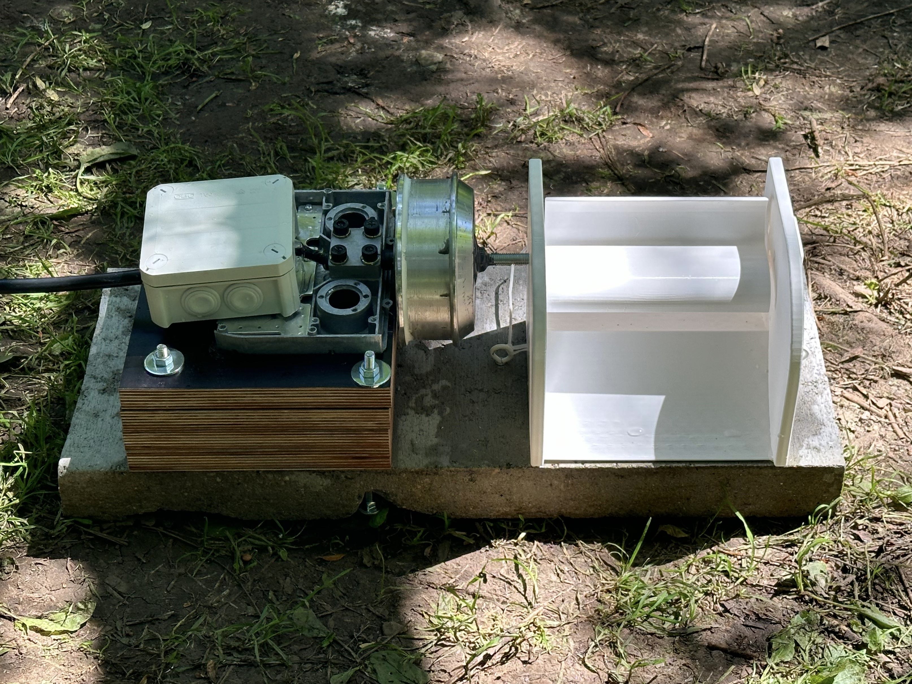
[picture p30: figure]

Abbildung 29: Gebauter Turbogenerator

tor millimetergenau auf die Höhe der Drehachse der Turbine zu bringen, muss man die Unterseite des Metallgehäuses auf die richtige Höhe bringen, sodass die Turbinen- und Generatorachse auf einer Höhe sind. Die Drehachse der Turbine ist 107,0 mm hoch und die Drehachse des Generators ca. 23 mm von der Unterseite des Metallgehäuses entfernt. Dementsprechend muss das Gehäuse des Hoverboards um 107 mm - 23 mm = 84 mm erhöht werden. Dies erfolgt durch 4 21 mm dicke MDF Platten, die übereinander geschraubt werden.

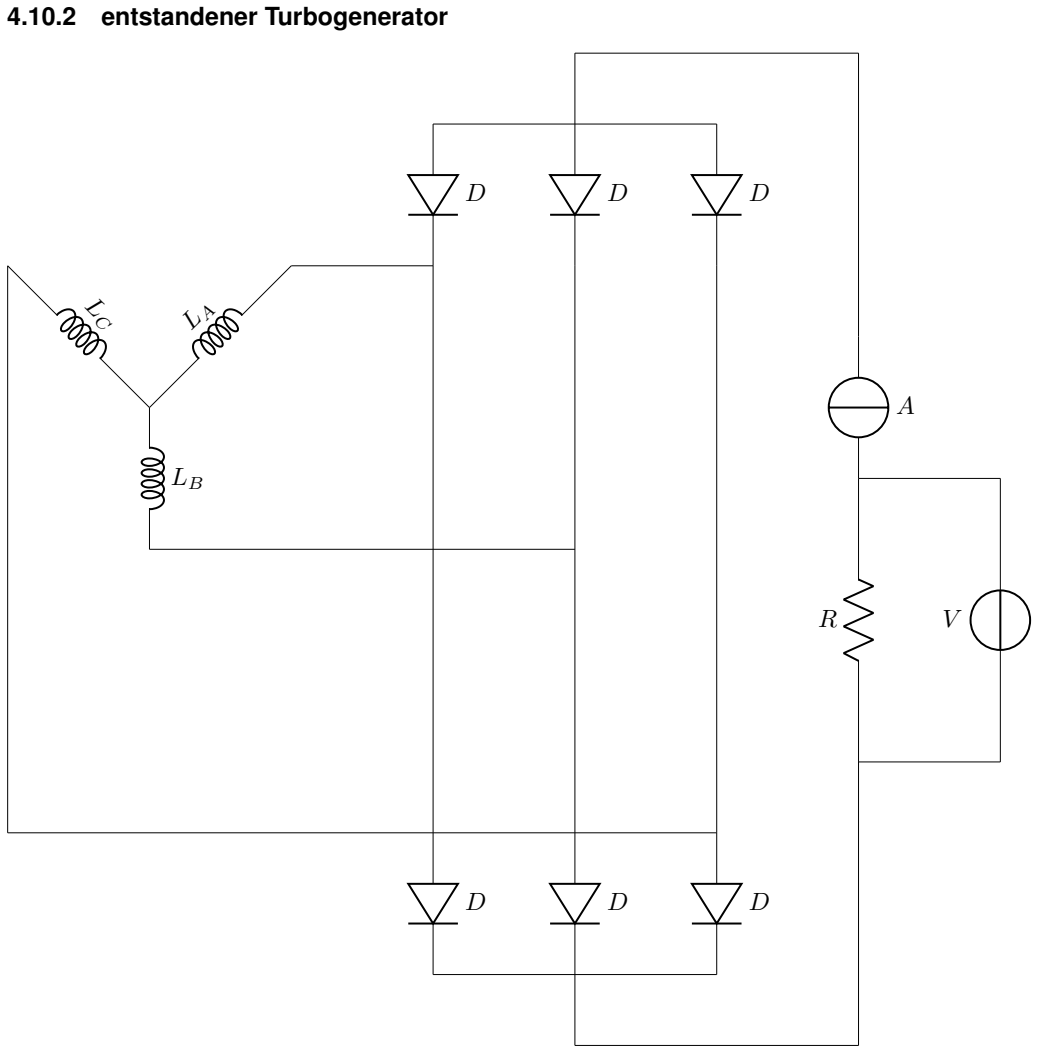
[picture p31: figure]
4.10.2 entstandener Turbogenerator

Gesamter Schaltkreis des Turbogenerators gezeichnet mit Circuitikz

## 5 Ergebnisse - Analyse und kritische Betrachtung

### 5.1 Masse der Turbinen

Anhand von Abb. 30 kann man sehen, dass es einen klaren Zusammenhang zwischen Anzahl der Turbinenblätter und ihrem Gewicht gibt. Des Weiteren ist die Turbine mit Leitblech deutlich schwerer als die Dreiblättrige ohne. Daher führt die Verwendung von Leitblechen zu höheren Belastungen für den Generator.

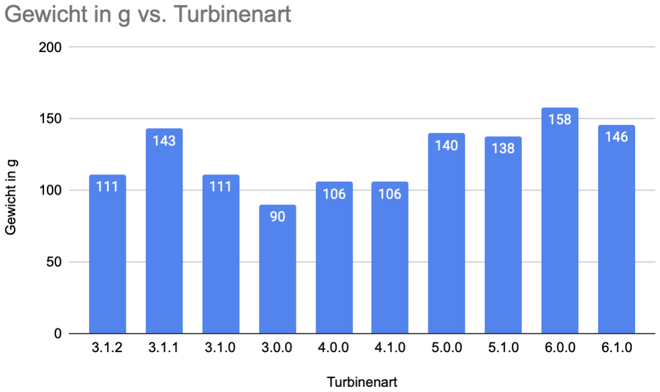
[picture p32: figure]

Abbildung 30: Gewicht der Turbinen

Bei der Beschriftung der Turbinen steht die erste Zahl für die Anzahl an Turbinenblättern. Die zweite Zahl sagt aus, ob die Turbine gekrümmte (1) oder gerade (0) Blätter hat, und die dritte Zahl sagt aus, ob die Turbine zusätzlich verkleinerte Blätter (2), Leitbleche (1) oder keinen Zusatz hat (0).

### 5.2 Test in Werkstattbedingungen

Die Ergebnisse des Generators in Werkstattbedingungen sind sehr vielversprechend. Der Generator inklusive Vollbrückenschaltung funktionierte in Werkstattbedingungen einwandfrei. Mithilfe eines Multimeters und eines Widerstandes von 20 Ohm haben sich bei manuellem Drehen des Generators (von Hand) Spannungen, U, von bis zu 4,19 V und Stromstärken, I von bis zu 3,41 A messen lassen. Somit lag die Leistung bei:

P = U · I = 4, 19V · 3, 41A = 14, 2879W

Um die volle Leistungsfähigkeit des Generators zu bestimmen, müsste man seine Leistung unter verschiedenen Lastbedingungen und insbesondere bei einer höheren Drehzahl messen.

### 5.3 Standortauswahl

Die Auswahl des Standorts basiert auf der Strömungsgeschwindigkeit des Flusses und anderen Umweltfaktoren. Es ist wichtig anzumerken, dass die Strömungsgeschwindigkeit nicht der einzige entscheidende Faktor ist. Auch die Gleichmäßigkeit des Flusses und potenzielle Hindernisse wie Steine sollten berücksichtigt werden, um eine optimale Leistung des Turbogenerators sicherzustellen.

Aus diesen Gründen habe ich die Adresse Am Angelpark, 50126 Bergheim ausgewählt. Dort befindet sich die Erft, die an dieser Stelle eine Abflussgeschwindigkeit von 9,6 m³/s hat. Die Was-

sergeschwindigkeit habe ich näherungsweise mit einem Blatt gemessen. Für 10 Meter brauchte das Blatt ca. 6,81 Sekunden. Somit beträgt die Wassergeschwindigkeit des Flusses ungefähr:

10 m
6, 81 s

= 1, 468 m/s

Dies ist eine sehr geeignete Flussgeschwindigkeit, denn einerseits darf die Geschwindigkeit nicht zu groß sein, um nicht die Drehung der Turbine durch eine Überschreitung der Achslast

zu blockieren. Andererseits muss die Flussgeschwindigkeit schnell genug sein, damit sich die Turbine drehen kann.Am Fluss habe ich dann eine Stelle ausgesucht, an der das Wasser nicht zu tief war und die Strömung die Turbine geradlinig trifft.

### 5.4 Test in Realbedingungen

Zunächst wurde der Turbogenerator so ausgerichtet, dass er mit stabilem Stand orthogonal zur Strömung stand und sich deutlich unter der Wasseroberfläche (Oberkante 20 cm unter Wasseroberfläche) befand. Dabei stellte sich heraus, dass die Strömungskraft nicht in der Lage war, den Widerstand der Turbine zu überwinden. Die Turbine bewegte sich nicht. Es erfolgte ein manueller Test. Durch manuelles Andrehen der Turbine drehte sich die Turbine anschließend noch weitere 1-2 Sekunden, die Bewegung erlag dann aber dem Widerstand des Generators. Wie unter Werkstattbedingungen konnte aber mittels Messung im Wasser erneut demonstriert werden, dass der hydrokinetische Turbogenerator funktionstüchtig und vor allem entgegen meiner größten Sorge wasserdicht war. Mittels Multimeter konnten eine Spannung von ca. 1,64 V und eine Stromstärke von ca. 1.21 A dokumentiert werden. Somit ließ sich eine Gesamtleistung von P = 1, 64V · 1.21A = 1, 9844W berechnen. Diese Größen waren direkt proportional abhängig von der Geschwindigkeit, mit der das Generatorrad von Hand unter Wasser gedreht wurde.

### 5.4.1 Ermittlung des Leistungskoeffizients

Die Ermittlung des Leistungskoeffizients ist in diesem Fall nicht möglich, da keine echte Leistung ermittelt werden konnte, müsste aber wie folgt ermittelt werden:

Perzeugt = 0, 5 · ρ · A · Cp · V

3

Daraus folgt:

Cp =

Perzeugt
0, 5 · ρ · A · V ³

Für mein Beispiel wäre es dann:

Cp =

Perzeugt
0, 5 · 1000 kg/m³
- 0, 01439m² · (1, 468 m/s)

3

### 5.4.2 Prohizierte Stromerzeugungsleistung

Nimmt man an, dass CP bei ca. 0.1 liegt, so erreicht man folgende Leistung:

Perzeugt = 0.5 · 1000 kg/m³
- 0.01439 m²
- (1.468 m/s)

3 = 2.2799 W

Dieses Ergebnis ist 0,2955 W mehr als der gemessene Wert beim manuellen Drehen erreicht wurde. Dies könnte sowohl daran liegen, dass der Leistungskoeffizient nur eine Näherung ist, als auch daran, dass sich die Turbine nach dem manuellen Andrehen sofort entschleunigt und die Leistung dementsprechend sofort weniger wird.

### 5.5 Anmerkungen

Beim Bau des Prototypen mussten immer wieder Modifikationen des ursprünglichen Designs erfolgen, da das Design unter Realbedingungen nicht praxistauglich war. Dazu gehörten unter anderem: Ursprünglich war keine Bodenplatte aus Beton geplant. Zur Gewichtserhöhung, Stabilisierung und Versteifung der Gesamtkonstruktion habe ich eine Betonbodenplatte aus dem, Baumarkt besorgt. Mit Hilfe einer Flex wurde diese auf die richtige Größe angepasst. Um nun den Generator mit Gewindestange millimetergenau auf die Höhe der Turbinenachse (8,4 cm) zu bringen, wurde die Höhe über MDF-Platten (2,1cm) erreicht. Ursprünglich hatte ich geplant, den Generator mittels Stangen durch die Einlässe am Gehäuse (Abb. 13, A) im Boden zu verankern. Dies war so durch die Betonplatte nicht mehr möglich. Es musste eine andere Befestigung her. Dabei ergab sich als weiteres Problem, dass das Turbinengehäuse reversibel befestigt werden musste, um die verschiedenen Turbinen einbauen zu können. Darum habe ich vier Ringschrauben in der Betonplatte verschraubt. Je eine Ringschraube auf jeder Seite der Ösen. Perfekt wäre

ein Schienensystem, über das das Turbinengehäuse seitlich aufgeschoben werden könnte. Eine Verschweißung wäre sicher noch besser, stand mir aber nicht zur Verfügung.

## 6 Fazit

Der von mir entwickelte und gebaute hydrokinetische Turbogenerator konnte unter Realbedingungen keinen Strom erzeugen. Allerdings war der Turbogenerator prinzipiell sowohl über wie unter Wasser in der Lage, Strom zu erzeugen. Insofern ist das Experiment aus meiner Sicht erfolgreich. Der Generator funktioniert, nur ist das Verhältnis zwischen der elektromotorischen Kraft und der Turbinengröße unzureichend. Es hat sich mir die Frage gestellt, ob ich im Vorfeld durch Berechnung der elektromotorischen Kraft des Generators und Antriebskraft der Turbine die Verhältnisse (Generatorstärke, Größe der Turbinen) eventuell hätte berechnen können. Hierzu habe ich aber keine Literatur finden können. Allerdings musste ich mit einem vorgegebenen Generator aus einem kaputten Hoverboard, das ich über eBay erstanden habe, arbeiten. Der Kauf eines wasserdichten Generators aus dem Fachhandel wie auch größere Turbinen hätten meine finanziellen Möglichkeiten innerhalb des Projektes gesprengt. Als Schlussfolgerung ergibt sich: Eine kontinuierliche, unabhängige Stromproduktion mit diesem Prototyp eines Turbogenerators wäre über zwei Wege zu erreichen.
1. Die Turbinen müssten deutlich vergrößert werden. Dadurch wäre die Antriebsfläche größer und der Widerstand des Hoverboardgenerators würde überwunden werden. 2. Man müsste den Generator gegen einen schwächeren (weniger bzw. schwächere Magneten) austauschen. In diesem Fall wäre die Antriebskraft der Turbinen ausreichend.
Unter Berücksichtigung dieses Experiments ist es nun möglich, einen funktionstüchtigen Nachfolger zu bauen. Würde man dieses Experiment nach streng wissenschaftlichen Bedingungen durchführen müssen, wäre ein standardisierter Versuchsaufbau erforderlich. Gefordert wären Objektivität, Reliabilität und Validität. Mein Experiment ist nach meinem Verständnis objektiv und valide, aber nicht reliabel. Hierzu wäre ein Versuchsaufbau wie folgt erforderlich: Ein Wasserkanal, in dem der Generator fest verankert wird und mit den verschiedenen Turbinen durchgemessen wird. Dabei müssten Strömungen (laminar oder turbulent) und Geschwindigkeit zuverlässig über eine Strömungsmaschine eingestellt werden können.
Des Weiteren könnten die Turbinendesgins über eine computergestützte Fluidsimulation (CFD) Simulation auf ihre Effizienz getestet werden. Auf diese Weise könnte ein standardisierter Versuch stattfinden. Leider benötigt eine CFD-Simulation jedoch eine Expertise in Fluiddynamik, die den schulischen Rahmen bei Weitem sprengt.
Um den gesamten Turbogenerator langlebiger zu machen, könnte man einiges modifizieren. Die Gewindestange wäre deutlich sicherer angebracht, wenn sie an das Hoverboardrad geschweißt wäre. Die Turbinen und Halterung könnten durch maschinelle Fertigung ebenfalls langlebiger werden, wenn sie aus einem stabileren Material gefertigt werden würden. Letztendlich schafft der gebaute Turbogenerator es zwar nicht, kontinuierlich Strom zu produzieren, doch das Design kann prinzipiell in Krisensituationen für kritische Stromversorgung genutzt werden. Hierfür müssten nur die genannten Modifikationen erfolgen.

## 7 Literaturverzeichnis

## Literatur

[1] International Energy Agency. World Energy Outlook 2023. Licence: CC BY 4.0 (report); CC

BY NC SA 4.0 (Annex A). Paris: IEA, 2023. URL: https://www.iea.org/reports/world-

energy-outlook-2023.

[2] IEA. Total primary energy supply by fuel, 1971 and 2019. Licence: CC BY 4.0. Paris, 2021.

URL: https://www.iea.org/data- and- statistics/charts/total- primary- energy-

supply-by-fuel-1971-and-2019.

[3] Saher Ayyad und Muhammad Khalifa. “Will the Eastern Nile countries be able to sustain their crop production by 2050? An outlook from water and land perspectives”. In: Science of the Total Environment 775 (2021), S. 145769.
[4] MTH Van Vliet u. a. “Multi-model assessment of global hydropower and cooling water discharge potential under climate change”. In: Global Environmental Change 40 (2016), S. 156– 170.
[5] Christiane Zarfl u. a. “A global boom in hydropower dam construction”. In: Aquatic Sciences 77 (2015), S. 161–170.
[6] MP McCartney u. a. “Ecosystem impacts of large dams”. In: Background paper 2 (2001).
[7] Wasserkraftverband Mitteldeutschland e.V. Die Francis-Turbine. https://www.wasserkraftverband.de/francis-turbine/. Accessed: 2024-06-06. 2024.
[8] Institut für Hydraulische Strömungsmaschinen der Technischen Universität Graz. Francis-

Turbine. https://www.hfm.tugraz.at/de/studium-weiterbildung/begriffserklaerungen/francis-turbine.html. Accessed: 2024-06-06. 2024.

[9] Wasserkraftverband Mitteldeutschland e.V. Kaplan-Turbine. https://www.wasserkraftverband.de/kaplan-turbine/. Accessed: 2024-06-06. 2024.
[10] Verbund AG. Kaplan-Turbine. https : / / www . verbund . com / de - de / ueber - verbund /

kraftwerke/turbinen/kaplan#:~:text=SomitkanneinWirkungsgradvon,undschwankendenDurchflussmengengutarbeitet. Accessed: 2024-06-06. 2024.

[11] Wasserkraftverband Mitteldeutschland e.V. Pelton-Turbine. https://www.wasserkraftverband.
de/pelton-turbine/. Accessed: 2024-06-06. 2024.
[12] Verbund AG. Pelton-Turbine. https://www.verbund.com/de. Accessed: 2024-06-06. 2024.
[13] Bayerische Landeskraftwerke. Durchströmturbine Ossberger. https://www.landeskraftwerke.

bayern/durchstroemturbine-ossberger.htm. Accessed: 2024-06-06.

[14] J Krishnaraj, Sivakumar Ellappan und M Anil Kumar. “Additive manufacturing of a gorlov helical type vertical axis wind turbine”. In: International Journal of Engineering and Advanced Technology 9.2 (2019), S. 2639–2644.
[15] E Chica u. a. “Design of a hydrokinetic turbine”. In: WIT Transactions on Ecology and the Environment 195 (2015), S. 137–148.
[16] Herman Jacobus Vermaak, Kanzumba Kusakana und Sandile Philip Koko. “Status of microhydrokinetic river technology in rural applications: A review of literature”. In: Renewable and Sustainable Energy Reviews 29 (2014), S. 625–633.
[17] Studyflix. Generator Physik. https://studyflix.de/elektrotechnik/generator-physik-5740. Accessed: 2024-06-06.

[18] bramesh501. Bottle Cap and neck PCO 1881. Accessed: 2024-05-30. 2017. URL: https:

//www.thingiverse.com/thing:2203127/files.

[19] igus. Xiros Radial Gleitlager. https://www.igus.de/product/xiros_radial_B180_GL_

B180?artnr=BB-686-B180-30-GL. Accessed: 2024-06-06.

[20] Filamentpreis. PETG - das Allround-Filament. Accessed: 2024-05-30. 2024. URL: https:

//www.filamentpreis.de/materialien/petg/.

[21] Electronics Tutorials. Three Phase Rectification. Accessed: 2024-06-06. URL: https : / /

www.electronics-tutorials.ws/power/three-phase-rectification.html.

[22] Quora. How can I convert a 3 phase AC to a single phase DC? Accessed: 2024-06-06. URL:

https://www.quora.com/How-can-I-convert-a-3-phase-AC-to-a-single-phase-DC.

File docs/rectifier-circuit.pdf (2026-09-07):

\begin{circuitikz}
% Drawing the coils (inductors) in a star formation \draw (0,0) to[L, l=$L_A$] (2,2);
\draw (0,0) to[L, l=$L_B$] (0,-2);
\draw (-2,2) to[L, l=$L_C$] (0,0);

%connecting to full bridge rectifier
\draw (2,2) -- (4,2);
\draw (-2,2)--(-2,-6);
\draw (0,-2)--(4,-2) to[bend left] (4,-2)--(6,-2); \draw (-2,-6)--(8,-6);

% Drawing full bridge
\draw (4,4) to[D, l=$D$] (4,2);
\draw (4,2)--(4,-6);
\draw (4,-6) to[D, l=$D$] (4,-8);

\draw (6,4) to[D, l=$D$] (6,2); \draw (6,2)--(6,-6);
\draw (6,-6) to[D, l=$D$] (6,-8);

\draw (8,4) to[D, l=$D$] (8,2); \draw (8,2)--(8,-6);
\draw (8,-6) to[D, l=$D$] (8,-8);

%connect lower 3
\draw (4,-8)--(8,-8);
\draw (6,-8)--(6,-9);
\draw (6,-9)--(10,-9);
\draw (10,-9)--(10,-5);
\draw (10,-5)to[R, l=$R$](10,-1);

%connect upper 3
\draw (4,4)--(8,4);
\draw (6,4)--(6,5);
\draw (6,5)--(10,5);
\draw (10,5)--(10,1);
\draw (10,1)to[I, l=$A$](10,-1);

%volt in parrallel
\draw (10,-5)--(12,-5);
\draw (12,-5)to[V, l=$V$](12,-1); \draw (12,-1)--(10,-1);
\end{circuitikz}

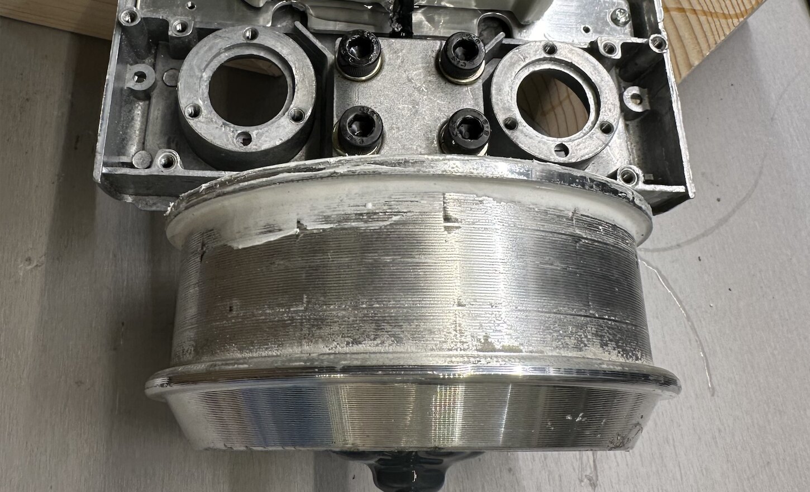
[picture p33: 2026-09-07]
docs/photos/04-generator-hub.jpg

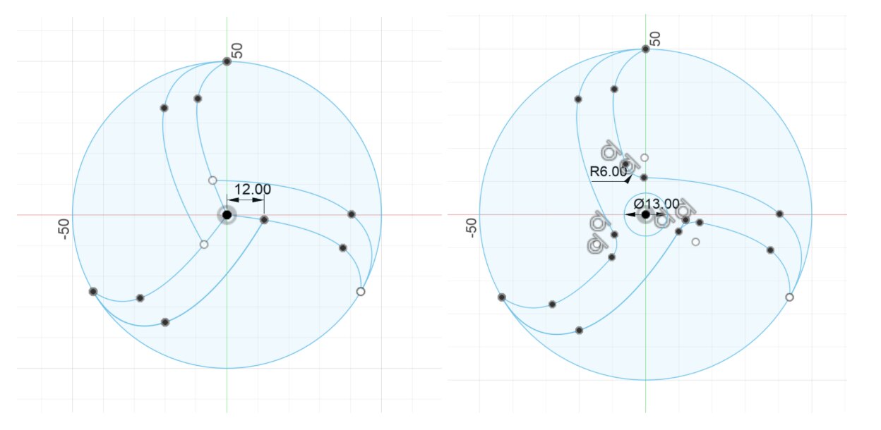
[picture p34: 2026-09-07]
docs/photos/12-blade-profiles.jpg

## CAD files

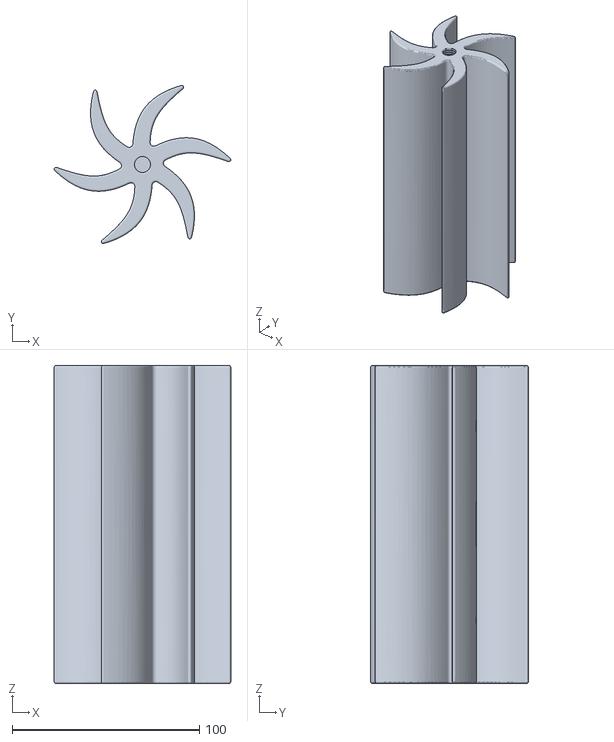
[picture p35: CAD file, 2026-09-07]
cad/REBELWORKS_6_CURVED.stl
94.5 x 84.5 x 170.0

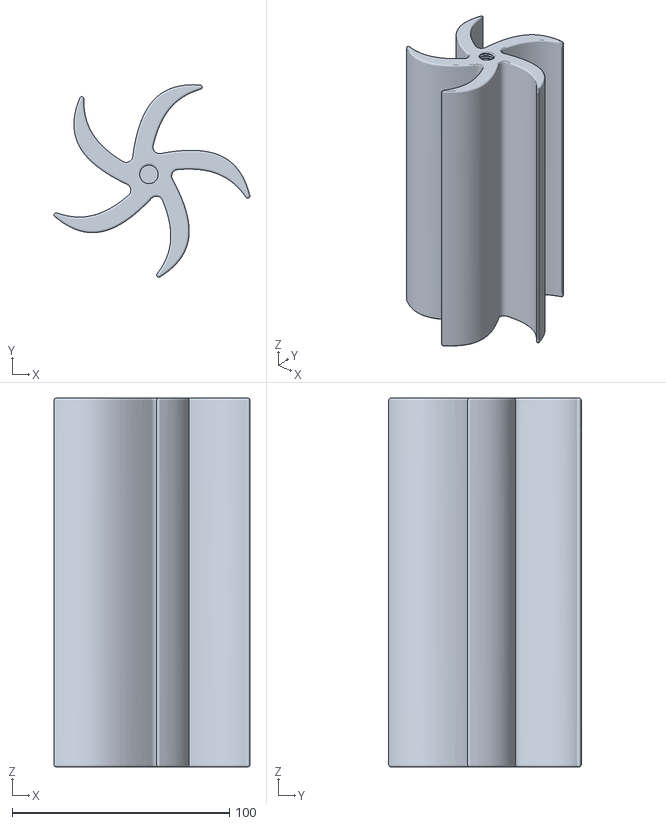
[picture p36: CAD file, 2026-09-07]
cad/REBELWORKS_5_CURVED.stl
90.2 x 88.7 x 170.0

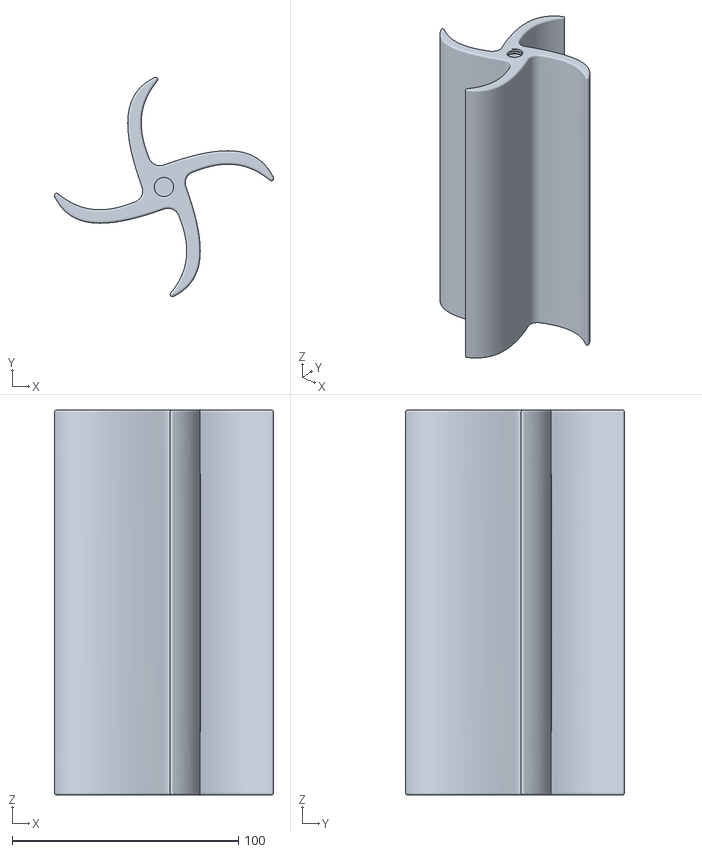
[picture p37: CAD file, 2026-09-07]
cad/REBELWORKS_4_CURVED.stl
96.9 x 96.9 x 170.0

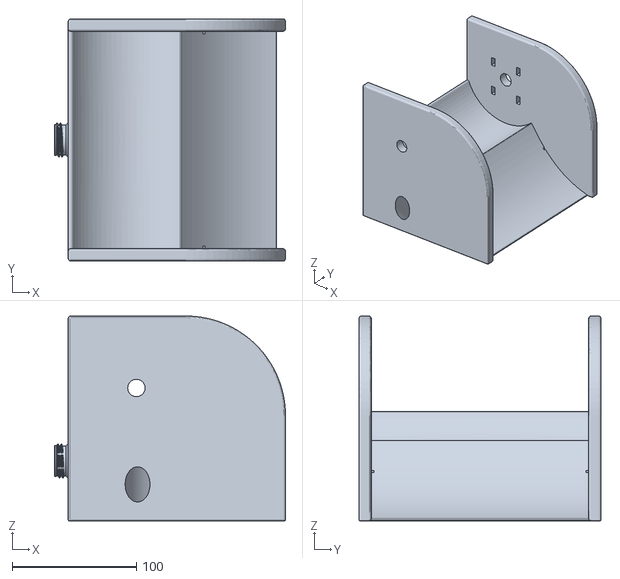
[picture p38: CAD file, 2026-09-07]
cad/REBELWORKS_HALTERUNG.stl
186.0 x 195.0 x 165.0

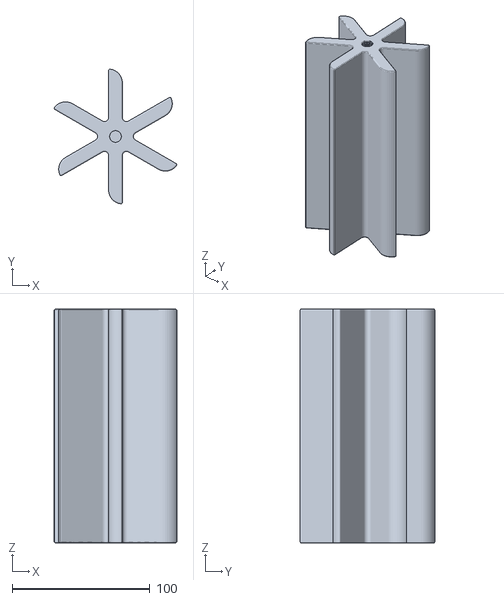
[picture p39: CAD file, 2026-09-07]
cad/REBELWORKS_6_STRAIGHT.stl
89.0 x 97.9 x 170.0

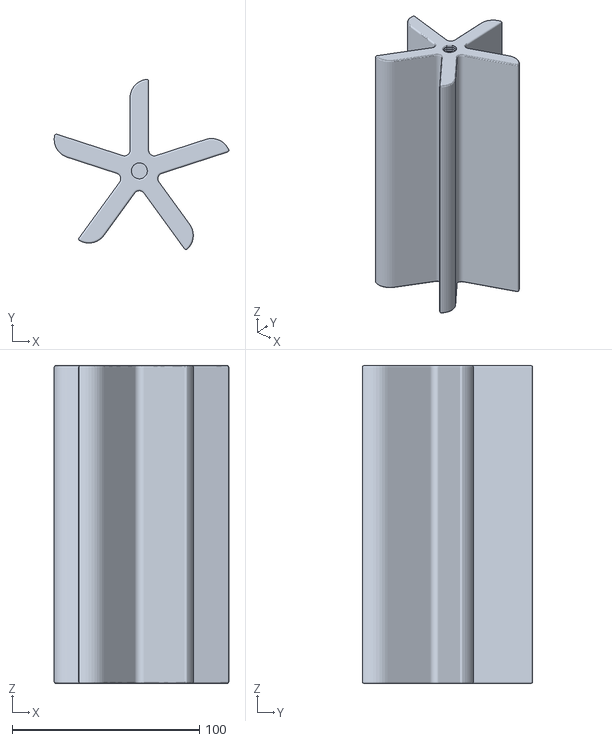
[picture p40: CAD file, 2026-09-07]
cad/REBELWORKS_5_STRAIGHT.stl
93.4 x 91.1 x 170.0

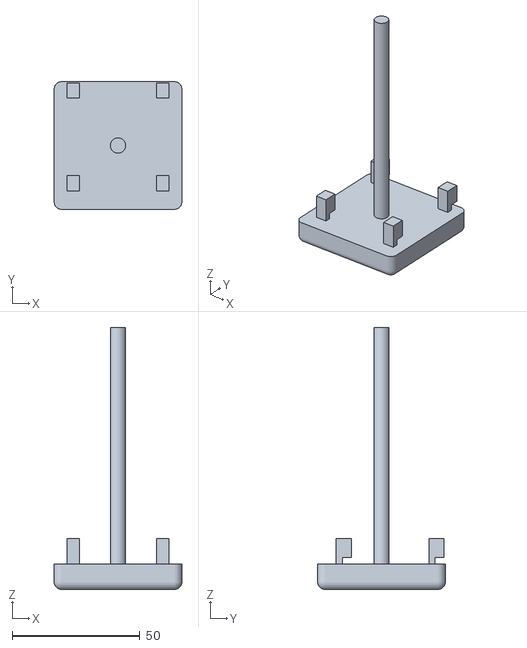
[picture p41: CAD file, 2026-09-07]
cad/REBELWORKS_STAB.stl
50.0 x 50.0 x 102.5

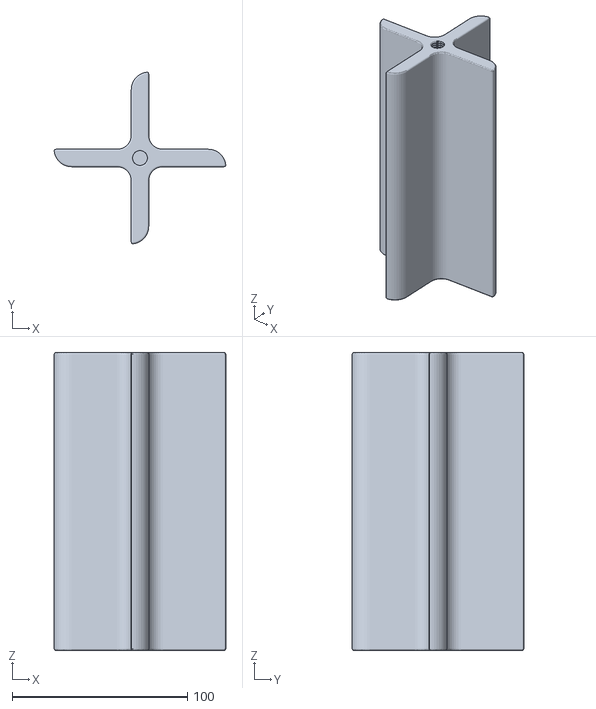
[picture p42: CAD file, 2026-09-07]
cad/REBELWORKS_4_STRAIGHT.stl
97.9 x 97.9 x 170.0

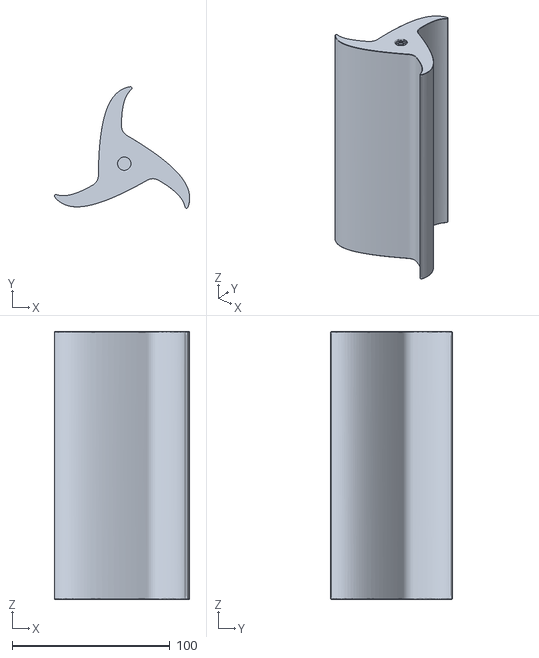
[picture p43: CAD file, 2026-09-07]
cad/REBELWORKS_3_CURVED_HIGH_MASS.stl
85.9 x 77.1 x 170.0

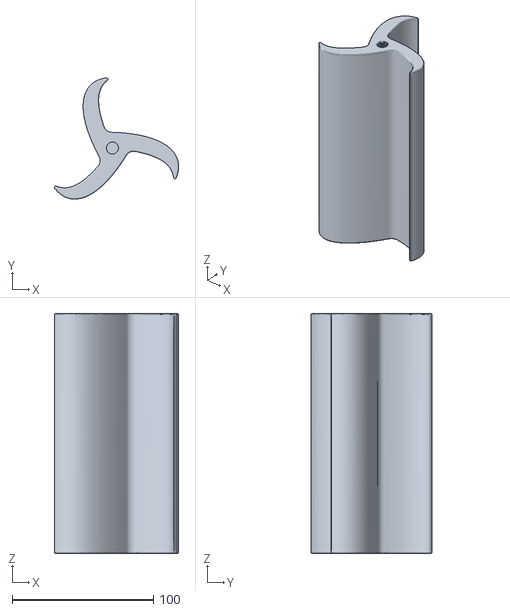
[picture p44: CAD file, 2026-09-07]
cad/REBELWORKS_3_CURVED.stl
88.0 x 85.9 x 170.0

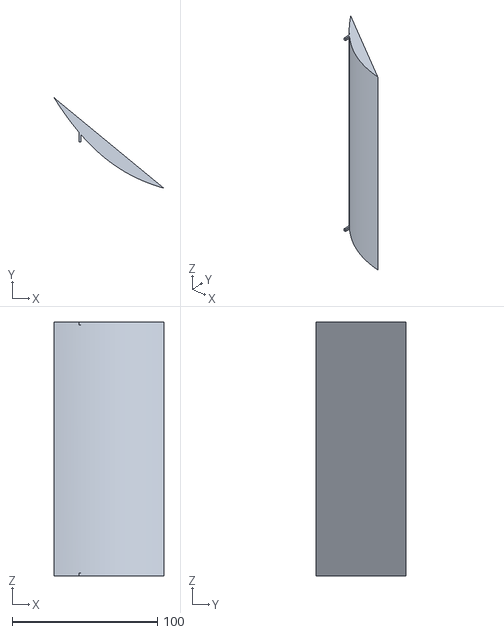
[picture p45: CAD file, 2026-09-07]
cad/REBELWORKS_GERADE.stl
75.7 x 62.3 x 175.0

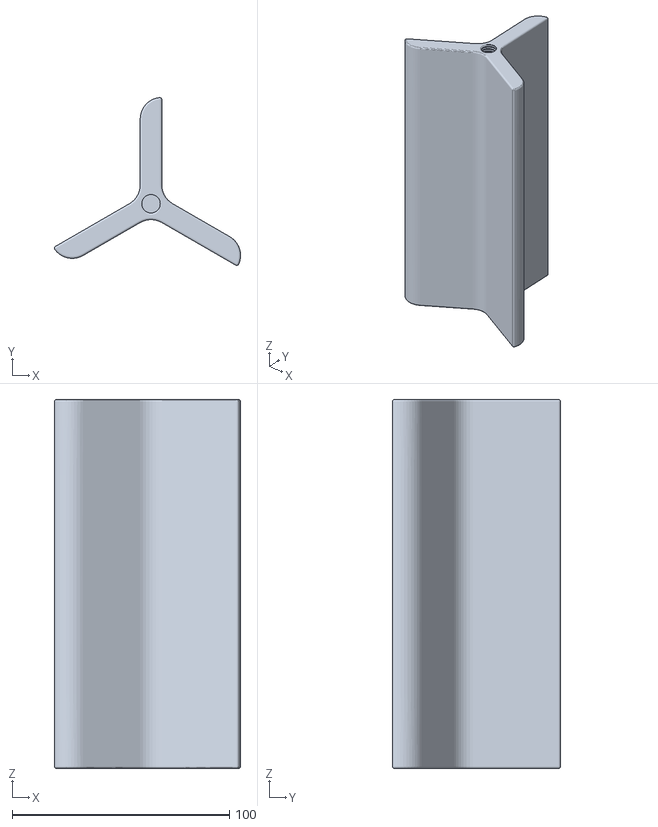
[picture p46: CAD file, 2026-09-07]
cad/REBELWORKS_3_STRAIGHT.stl
85.8 x 77.4 x 170.0

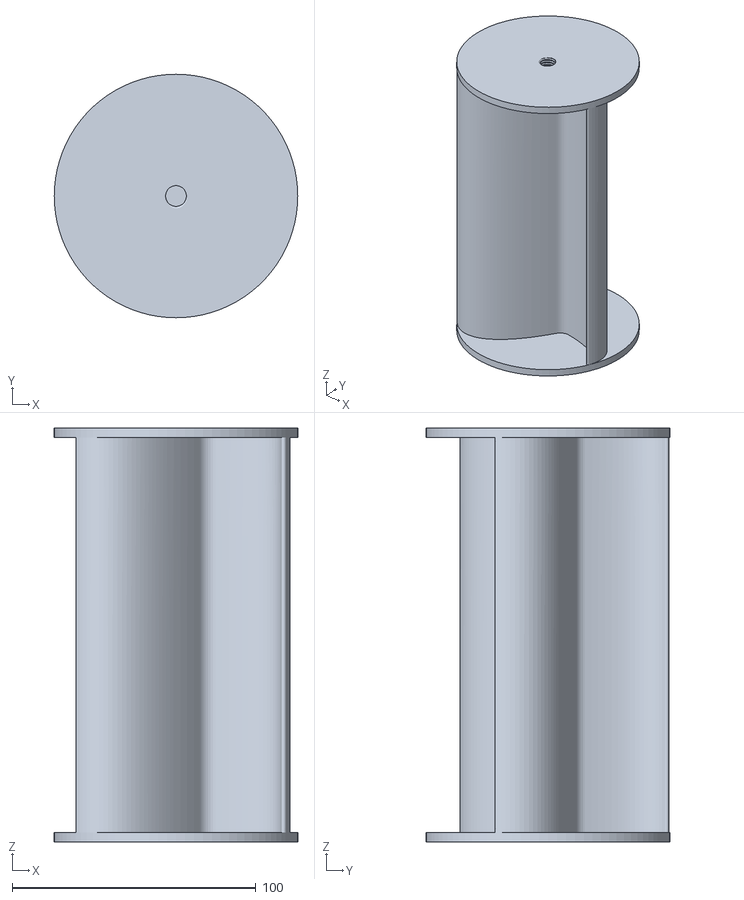
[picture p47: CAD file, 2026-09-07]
cad/REBELWORKS_3_CURVED_BAFFLES.stl
100.0 x 100.0 x 170.0
